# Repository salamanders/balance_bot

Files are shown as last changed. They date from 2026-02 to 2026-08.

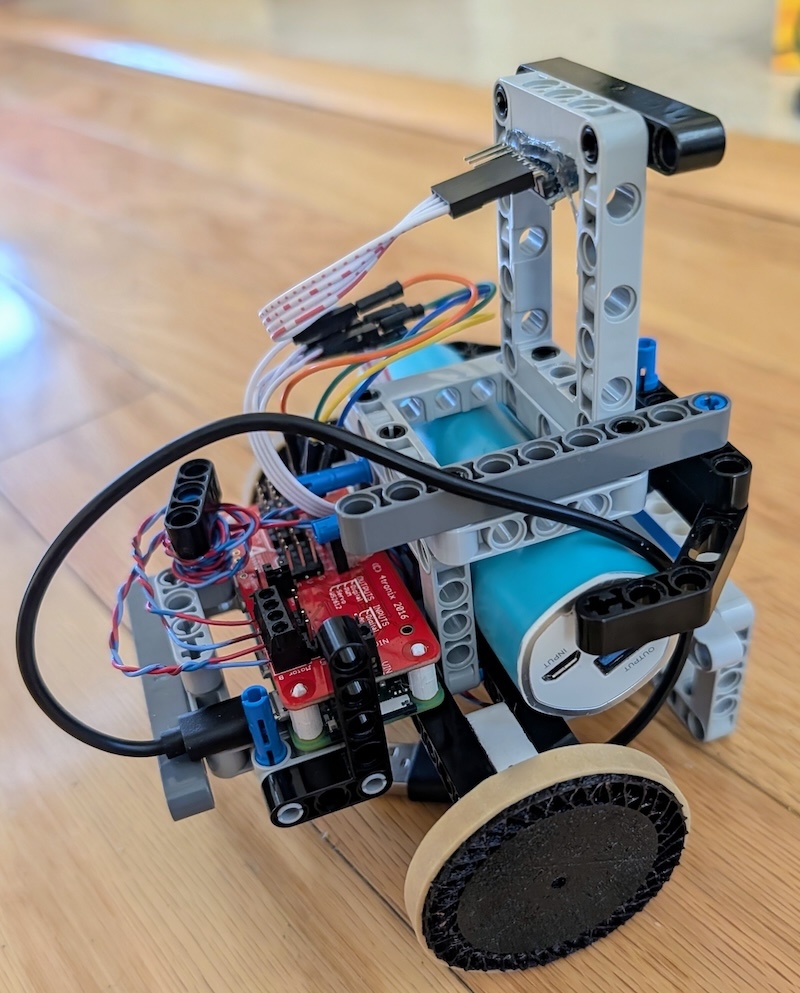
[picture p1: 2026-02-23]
robot.jpg

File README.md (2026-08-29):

# balance_bot

Self-balancing homebrew Segway robot powered by a Raspberry Pi, 4tronix PiconZero HAT, MPU-6050 IMU, and 3D-printed/LEGO mechanical topology.

> **Note for Developers and Autonomous Agents:**
> * For engineering governance, LLM directives, Multi-Mind subsumption architecture, Tabula Rasa self-discovery, empirical hardware rules, and codebase assumptions, see [AGENTS.md](file:///Users/benhill/Desktop/hobbies/balance_bot/AGENTS.md).
> * For the chronological log of physical experiments, hardware audits, bug investigations, and empirical lessons learned, see [JOURNAL.md](file:///Users/benhill/Desktop/hobbies/balance_bot/JOURNAL.md).

---

## References

### Root Directory

* [.gitignore](file:///Users/benhill/Desktop/hobbies/balance_bot/.gitignore): Git configuration specifying which files to ignore.
* [.python-version](file:///Users/benhill/Desktop/hobbies/balance_bot/.python-version): Specifies the Python version used by the project/tools.
* [AGENTS.md](file:///Users/benhill/Desktop/hobbies/balance_bot/AGENTS.md): Comprehensive engineering manual, LLM governance rules, system architecture, systemd auto-run instructions, and blind spot documentation.
* [JOURNAL.md](file:///Users/benhill/Desktop/hobbies/balance_bot/JOURNAL.md): Chronological engineering log of physical experiments, empirical hardware audits, bug investigations, and learnings.
* [LICENSE](file:///Users/benhill/Desktop/hobbies/balance_bot/LICENSE): Project license file.
* [Makefile](file:///Users/benhill/Desktop/hobbies/balance_bot/Makefile): Shortcut commands for installation, linting, formatting, and running.
* [README.md](file:///Users/benhill/Desktop/hobbies/balance_bot/README.md): The main entry point documentation.
* [environment.sh](file:///Users/benhill/Desktop/hobbies/balance_bot/environment.sh): Script to set up the development environment (system dependencies, uv).
* `pid_config.json`: Persisted storage for the tuned PID parameters.
* [pyproject.toml](file:///Users/benhill/Desktop/hobbies/balance_bot/pyproject.toml): Python project configuration, dependencies, and tool settings.
* [setup.sh](file:///Users/benhill/Desktop/hobbies/balance_bot/setup.sh): Initial system setup script (I2C enablement, system libraries).
* [uv.lock](file:///Users/benhill/Desktop/hobbies/balance_bot/uv.lock): Dependency lock file to ensure reproducible installs.

### Source Code (`src/balance_bot`)

**Core & Utilities**
* [src/balance_bot/__init__.py](file:///Users/benhill/Desktop/hobbies/balance_bot/src/balance_bot/__init__.py): Package initialization.
* [src/balance_bot/configuration.py](file:///Users/benhill/Desktop/hobbies/balance_bot/src/balance_bot/configuration.py): Centralized configuration (constants, dataclasses) for the robot.
* [src/balance_bot/enums.py](file:///Users/benhill/Desktop/hobbies/balance_bot/src/balance_bot/enums.py): Enumerations for direction and orientation.
* [src/balance_bot/jules_client.py](file:///Users/benhill/Desktop/hobbies/balance_bot/src/balance_bot/jules_client.py): Client for reporting crashes to Jules.
* [src/balance_bot/main.py](file:///Users/benhill/Desktop/hobbies/balance_bot/src/balance_bot/main.py): Main application entry point.
* [src/balance_bot/utils.py](file:///Users/benhill/Desktop/hobbies/balance_bot/src/balance_bot/utils.py): Shared utility functions (math, timing, filtering).
* [src/balance_bot/wiring_check.py](file:///Users/benhill/Desktop/hobbies/balance_bot/src/balance_bot/wiring_check.py): Interactive tool for verifying motor/sensor wiring and orientation.

**Tier 1: Reflex (Brainstem)**
* [src/balance_bot/reflex/balance_core.py](file:///Users/benhill/Desktop/hobbies/balance_bot/src/balance_bot/reflex/balance_core.py): The high-frequency (100Hz) balance loop. Pure physics/math.
* [src/balance_bot/reflex/pid.py](file:///Users/benhill/Desktop/hobbies/balance_bot/src/balance_bot/reflex/pid.py): PID controller implementation.

**Tier 2: Adaptation (Cerebellum)**
* [src/balance_bot/adaptation/recovery.py](file:///Users/benhill/Desktop/hobbies/balance_bot/src/balance_bot/adaptation/recovery.py): Soft-start logic for recovering from a crash.
* [src/balance_bot/adaptation/tuner.py](file:///Users/benhill/Desktop/hobbies/balance_bot/src/balance_bot/adaptation/tuner.py): Automatic PID tuning logic (Continuous Tuner) and Balance Point Finder.
* [src/balance_bot/adaptation/battery.py](file:///Users/benhill/Desktop/hobbies/balance_bot/src/balance_bot/adaptation/battery.py): Logic for monitoring battery voltage and estimating charge.

**Tier 3: Behavior (Cortex)**
* [src/balance_bot/behavior/agent.py](file:///Users/benhill/Desktop/hobbies/balance_bot/src/balance_bot/behavior/agent.py): The "Brain" that orchestrates the robot. Handles scheduling, state management, and high-level goals.
* [src/balance_bot/behavior/leds.py](file:///Users/benhill/Desktop/hobbies/balance_bot/src/balance_bot/behavior/leds.py): Controls the Raspberry Pi status LEDs for feedback.

**Hardware Abstraction**
* [src/balance_bot/hardware/robot_hardware.py](file:///Users/benhill/Desktop/hobbies/balance_bot/src/balance_bot/hardware/robot_hardware.py): Hardware Abstraction Layer (HAL) managing sensors and motors.
* [src/balance_bot/hardware/piconzero.py](file:///Users/benhill/Desktop/hobbies/balance_bot/src/balance_bot/hardware/piconzero.py): Driver for the Picon Zero Motor HAT.
* [src/balance_bot/hardware/piconzero_adapter.py](file:///Users/benhill/Desktop/hobbies/balance_bot/src/balance_bot/hardware/piconzero_adapter.py): Adapter for Picon Zero to manage I2C retries and bus switching.
* [src/balance_bot/hardware/mocks.py](file:///Users/benhill/Desktop/hobbies/balance_bot/src/balance_bot/hardware/mocks.py): Mock hardware implementations.

### Tests (`tests/`)
* [tests/benchmarks/](file:///Users/benhill/Desktop/hobbies/balance_bot/tests/benchmarks): Benchmark tests for performance critical components.
* [tests/test_balance_core_params.py](file:///Users/benhill/Desktop/hobbies/balance_bot/tests/test_balance_core_params.py): Tests for balance core parameters.
* [tests/test_balance_finder.py](file:///Users/benhill/Desktop/hobbies/balance_bot/tests/test_balance_finder.py): Tests for the Balance Point Finder logic.
* [tests/test_battery.py](file:///Users/benhill/Desktop/hobbies/balance_bot/tests/test_battery.py): Unit tests for battery estimation logic.
* [tests/test_i2c_config.py](file:///Users/benhill/Desktop/hobbies/balance_bot/tests/test_i2c_config.py): Tests for I2C bus configuration logic.
* [tests/test_imu_logic.py](file:///Users/benhill/Desktop/hobbies/balance_bot/tests/test_imu_logic.py): Tests for IMU math and pitch calculation.
* [tests/test_imu_resilience.py](file:///Users/benhill/Desktop/hobbies/balance_bot/tests/test_imu_resilience.py): Tests for IMU error handling and resilience.
* [tests/test_imu_yaw_roll.py](file:///Users/benhill/Desktop/hobbies/balance_bot/tests/test_imu_yaw_roll.py): Tests for yaw and roll calculations.
* [tests/test_kickup_config.py](file:///Users/benhill/Desktop/hobbies/balance_bot/tests/test_kickup_config.py): Tests for kick-up configuration and logic.
* [tests/test_piconzero_driver.py](file:///Users/benhill/Desktop/hobbies/balance_bot/tests/test_piconzero_driver.py): Tests for the Picon Zero driver.
* [tests/test_startup_logic.py](file:///Users/benhill/Desktop/hobbies/balance_bot/tests/test_startup_logic.py): Tests for the robot startup sequence.
* [tests/test_tuner.py](file:///Users/benhill/Desktop/hobbies/balance_bot/tests/test_tuner.py): Tests for the PID auto-tuning logic.
* [tests/test_utils.py](file:///Users/benhill/Desktop/hobbies/balance_bot/tests/test_utils.py): Unit tests for helper functions (clamp, filters, etc.).
* [tests/test_wiring_check_bus.py](file:///Users/benhill/Desktop/hobbies/balance_bot/tests/test_wiring_check_bus.py): Tests for the wiring check tool's bus detection.

### Printed Parts (`printed_parts/`)
* [printed_parts/dcmotor.scad](file:///Users/benhill/Desktop/hobbies/balance_bot/printed_parts/dcmotor.scad): OpenSCAD source file for motor mount.
* [printed_parts/tpu_wheel.scad](file:///Users/benhill/Desktop/hobbies/balance_bot/printed_parts/tpu_wheel.scad): OpenSCAD source file for TPU wheel.
* [printed_parts/wheel_v3.3mf](file:///Users/benhill/Desktop/hobbies/balance_bot/printed_parts/wheel_v3.3mf): 3D model project file (3MF) for the wheel (v3).
* [printed_parts/wheel_v3.scad](file:///Users/benhill/Desktop/hobbies/balance_bot/printed_parts/wheel_v3.scad): OpenSCAD source file for wheel v3.
* [printed_parts/wheel_v3_project.3mf](file:///Users/benhill/Desktop/hobbies/balance_bot/printed_parts/wheel_v3_project.3mf): Alternative/Project 3MF file for the wheel (v3).

---

## Getting Started (First Time Setup)

Follow these steps to get your robot up and running from a fresh Raspberry Pi installation.

### 0. Physical Wiring Check

* **MPU-6050**: VCC to 3.3V, GND to GND, SDA to SDA, SCL to SCL.
* **Motors**: Plugged into Motor A and Motor B on the Picon Zero.

If you have a Picon Zero HAT, it blocks standard I2C pins. You can add a software-defined "bus 3" using reachable GPIO pins:
1. Edit boot firmware configuration:
   ```bash
   sudo nano /boot/firmware/config.txt
   ```
2. Scroll to the bottom and add this exact line:
   ```txt
   dtoverlay=i2c-gpio,bus=3,i2c_gpio_sda=17,i2c_gpio_scl=27,i2c_gpio_delay_us=5
   ```
   *(Note: `i2c_gpio_delay_us=5` sets the bus speed to approximately 100kHz. Increase to `10` if you still encounter I2C errors.)*

### 1. Clone the Repository
```bash
git clone https://github.com/salamanders/balance_bot.git
cd balance-bot
```

### 2. Install `uv`
This project uses `uv` for Python dependency management:
```bash
curl -LsSf https://astral.sh/uv/install.sh | sh
```

### 3. System Setup
Run the setup script to enable I2C and install necessary system libraries:
```bash
chmod +x setup.sh
sudo ./setup.sh
```

### 4. Install Dependencies
```bash
uv sync
```

### 5. Verify & Run (Zero-Knowledge Self-Discovery)
Run the **Zero-Knowledge Self-Discovery Protocol**. This state-machine wizard automatically discovers your robot's unique motor wiring, polarity, MPU orientation, and friction thresholds on first boot:
```bash
uv run balance-bot
```
* The wizard is **pessimistic**: it verifies every discovery empirically before saving to `pid_config.json`.
* Once self-discovery completes, the main control loop wakes up and begins balancing automatically.
* For detailed documentation of the 7 self-discovery phases, see [AGENTS.md Section 5](file:///Users/benhill/Desktop/hobbies/balance_bot/AGENTS.md#5-the-tabula-rasa-protocol-zero-knowledge-self-discovery).

---

## CLI Execution & Flags

* `uv run balance-bot` — Runs standard self-discovery wizard or active balance control loop.
* `uv run balance-bot --deadman` — Enables the HTTP Deadman's Switch web interface (`http://<robot-ip>:8090`) for living room safety and remote data fetching.
* `uv run balance-bot --experiment-duration 4.0` — Enforces a global experiment timeout budget (e.g., 4.0s) across all phases.
* `uv run balance-bot --allow-mocks` — Runs control loop using Mock Hardware (required for CI / laptop testing without physical sensors/motors).
* `uv run balance-bot --reset-brain` — Wipes learned `pid_config.json` and forces re-running Tabula Rasa discovery.
* `uv run balance-bot --auto-fix` — Enables automated crash reporting and traceback submission to Jules.
* `uv run balance-bot --repl` — Launches interactive REPL for manual motor control, IMU reads, and gyro tests.

### Remote HTTP Data API (Port 8090)
When `--deadman` is active, the robot serves the following data endpoints over HTTP:
* `GET /flight_data.csv` (or `/data/flight`) — Raw 100Hz flight telemetry CSV.
* `GET /discovery_data.csv` (or `/data/discovery`) — Raw Tabula Rasa discovery calibration CSV.
* `GET /learning_state.json` (or `/data/learning_state`) — Current learned controller parameters and bumper angles.
* `GET /hardware_config.json` (or `/data/hardware_config`) — Physical hardware axis/bus mappings.
* `GET /data/analysis` — Automated blackbox forensic analysis JSON (kickup session breakdown, pulse metrics, failure classification).
* `GET /status` — Real-time pitch, posture, and deadman arming status.

---

## System Architecture, Governance & Empirical Rules

To eliminate duplication across documentation files, all system architecture details, multi-mind subsumption topology, AI agent governance directives, empirical hardware rules, systemd daemon deployment, and codebase assumptions are consolidated in [AGENTS.md](file:///Users/benhill/Desktop/hobbies/balance_bot/AGENTS.md):

* **[Project Philosophy & Hardware Reality](file:///Users/benhill/Desktop/hobbies/balance_bot/AGENTS.md#1-project-philosophy--hardware-reality)** — Bumpers, resting state vs. crash angle, kick-up maneuvers, and persistence.
* **[Mandatory LLM Directives & Code Standards](file:///Users/benhill/Desktop/hobbies/balance_bot/AGENTS.md#2-mandatory-llm-directives--code-standards)** — Pre-flight checks, type safety, SDD/RLVR, and anti-patterns.
* **[Mandatory Journaling Protocol](file:///Users/benhill/Desktop/hobbies/balance_bot/AGENTS.md#3-mandatory-journaling-protocol-journalmd)** — Requirements and formatting for logging experiments in `JOURNAL.md`.
* **[System Architecture & Multi-Mind Topology](file:///Users/benhill/Desktop/hobbies/balance_bot/AGENTS.md#4-system-architecture--multi-mind-topology)** — Tier 1 Brainstem (`100Hz`), Tier 2 Cerebellum (`~10Hz`), Tier 3 Cortex.
* **[Tabula Rasa Zero-Knowledge Bootstrapping](file:///Users/benhill/Desktop/hobbies/balance_bot/AGENTS.md#5-the-tabula-rasa-protocol-zero-knowledge-self-discovery)** — 7-phase self-discovery sequence and future Toddler Engine.
* **[Critical Cyber-Physical Blind Spots](file:///Users/benhill/Desktop/hobbies/balance_bot/AGENTS.md#6-critical-cyber-physical-blind-spots)** — Comprehensive comparison table of LLM biases vs. physical constraints.
* **[Immutable Empirical Hardware Rules](file:///Users/benhill/Desktop/hobbies/balance_bot/AGENTS.md#7-immutable-empirical-hardware-rules)** — PiconZero I2C register retention trap, LEGO mechanical backlash vs. `Kp`, tilt-chasing resonance in soft recovery, and the global 4-second chaos cutoff rule.
* **[Systemd Deployment & Automatic Startup](file:///Users/benhill/Desktop/hobbies/balance_bot/AGENTS.md#8-operations-systemd-deployment--manual-repl)** — Configuring `/etc/systemd/system/balance-bot.service` for auto-run on boot.
* **[Codebase Assumptions & Reference Citations](file:///Users/benhill/Desktop/hobbies/balance_bot/AGENTS.md#9-codebase-assumptions--reference-citations)** — I2C addresses, motor channels A/B, loop frequency, fall limit, default PID gains, and LED paths.

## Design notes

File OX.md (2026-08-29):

# OX.md - Balance Stabilization Strategy & Implementation Directive

> **Purpose:** This document is the authoritative engineering plan for achieving stable two-wheel
> balancing. It records the diagnosis, the reasoning behind every decision, the tradeoffs accepted,
> and the exact code changes required. It is written so that any agent (or human) can implement it
> without re-deriving the analysis.
>
> **Status:** Approved strategy (2026-08-22). Operator-confirmed dominant failure mode:
> **"Kick-up rarely succeeds - it never gets to vertical."**
> All downstream work (gains, damping, tuner) is unreachable until this gate is passed.
>
> **Governing rules:** All work must comply with [AGENTS.md](AGENTS.md) Sections 2, 6, and 7.
> Highlights enforced throughout this plan: no hardcoded physical constants, deadman switch AND/OR
> time budget on every physical trial, `make lint && make test` on all Python edits, mandatory
> JOURNAL.md entries per experiment, incrementalism over silver bullets, and confirmation of data
> interpretation with the operator before acting on telemetry.

---

## Table of Contents

1. [Diagnosis](#1-diagnosis-why-the-robot-cannot-balance)
2. [Strategy Overview & Phase Ordering](#2-strategy-overview--phase-ordering)
3. [Phase 0 Spec - Blackbox Forensics](#3-phase-0-spec---blackbox-forensics)
4. [Phase 1 Spec - State Estimation Fixes](#4-phase-1-spec---state-estimation-fixes)
5. [Phase 2 Spec - Rock-and-Flip Kick-Up](#5-phase-2-spec---rock-and-flip-kick-up)
6. [Phase 3+ Specs - Deferred Work](#6-phase-3-specs---deferred-work)
7. [Decision & Tradeoff Log](#7-decision--tradeoff-log)
8. [Validation Checklist & Journal Protocol](#8-validation-checklist--journal-protocol)

---

## 1. Diagnosis: Why The Robot Cannot Balance

Findings are ordered by causal priority. Each cites exact evidence locations.

### F0 - CRITICAL: The kick-up pulse collapses to ~one control tick (~10 ms)

**Evidence chain:**

* `src/balance_bot/behavior/states.py` lines 193-206 (`KickupState._incremental_kickup`):
  `context.core.hw.set_motors(drive_val, drive_val)` (pulse ON) immediately followed by
  `self._sleep_with_update(context, 0.25)` (intended 0.25 s pulse window).
* `states.py` lines 90 + 112-120: `_zero_motion_enabled` is
  `MotionRequest(velocity=0.0, turn_rate=0.0, enable_control=False)` and `_sleep_with_update`
  loops `context.core.update(self._zero_motion_enabled, ...)` every 10 ms.
* `src/balance_bot/reflex/balance_core.py` lines 149-163 (idle branch): when
  `motion.enable_control` is false the core **calls `self.hw.stop()` unconditionally, every tick**.

**Consequence:** On the first loop iteration after the pulse write, `core.update` writes zero.
The motor pulse lasts at most one loop period (`loop_time = 0.01 s`, configuration.py line 164)
plus I2C latency - not the intended 250 ms. A ~10 ms torque pulse cannot traverse LEGO gear
backlash, let alone rotate the chassis ~70 degrees from bumper rest to vertical. **This is the
leading hypothesis for the operator-confirmed failure mode.**

**Falsifiable prediction (verify in Phase 0 before touching anything):** in `flight_data.csv`,
each kick-up attempt should show non-zero `left_pwm`/`right_pwm` for only 1-2 consecutive rows.
If pulses actually last many rows, F0 is wrong; Phase 2 proceeds anyway (it removes the mechanism
entirely), but energy-delivery assumptions must be revisited.

### F1 - The kick-up sequence has no closed-loop timing

Independent of F0's duration bug, `_incremental_kickup` (states.py lines 173-221) fires a blind
fixed-duration pulse and only afterwards enters `_attempt_catch`. The robot never observes when
it crosses toward vertical:

* If the pulse carries the chassis past vertical sooner than assumed, gravity already pulls it
  over the wrong way before catch engages.
* If too weak, we wait out a full >= 1.25 s cycle (1.0 s settle + 0.25 s pulse + up to 2.5 s
  catch) before trying a bigger amplitude.
* With `kickup_power_forward/backward = 0.0` defaults (configuration.py lines 112-113), the
  search starts at zero power stepping 2% per cycle - tens of cycles, i.e., minutes, while the
  global `--experiment-duration` budget cuts runs short.

AGENTS.md Appendix A prescribes the fix ("Incremental Rock-and-Check Flip" with gyro feedback);
it was never implemented. Phase 2 implements it.

### F2 - Pitch estimate is corrupted exactly during kick-up/catch dynamics

`ComplementaryFilter` (utils.py lines 59-88) blends 2% raw accelerometer angle every tick
(alpha = 0.98, HardwareConfig line 165). During rotation, the MPU-6050 sits atop the tower
(r ~= 12-15 cm above the axle; AGENTS.md Rule 5), so tangential/centripetal acceleration dominates
the accelerometer and injects garbage into pitch precisely when closed-loop flip detection needs
it most. Additionally the filter initializes at `angle = 0.0` (utils.py line 75) while the robot
rests near -20 degrees on its bumpers; the 2 s warm-up (`setup_wait`) spends its early phase
recovering from a wrong prior instead of verifying calibration.

### F3 - The D-term is effectively absent (deferred - Phase 3a)

With degree units, `Kd = 0.5` contributes 30 PWM at a violent 60 deg/s fall rate while
`Kp = 10` contributes the same from only 3 degrees of tilt. An inverted pendulum is stabilized by
its derivative term; at these ratios the loop is nearly pure P, which on a backlash-y LEGO
drivetrain produces slam-oscillate-slam (JOURNAL 2026-08-02). Documented now so nobody re-litigates
it; addressed only after the kick-up gate passes.

### F4 - The auto-tuner cannot detect physical oscillation (deferred - Phase 3c)

`ContinuousTuner` analyzes a 1 s error buffer counting zero crossings against a 15% threshold
(configuration.py lines 65-66). A 1-2 Hz oscillation yields ~2-4 crossings per window - far below
threshold - so the "reduce Kp / boost Kd" heuristic rarely fires when needed. Kd nudges of +0.05
per event (50-tick cooldown) take many minutes of crashing to matter. Conclusion: **the tuner is a
trim tool, not a tuning tool**, and must not be relied on to rescue bad initial gains.

### F5 - No horizontal velocity handling (deferred - Phase 3b)

No encoders exist (PiconZero provides none), so once balanced the robot accelerates horizontally
until a wall or fall ends the run. Current mitigation (balance-point trim in
`BalancingState.update`, states.py lines 311-318) adjusts ~0.1 deg/s - orders of magnitude too slow
against runaway. Deferred until balancing itself works.

---

## 2. Strategy Overview & Phase Ordering

| Phase | Target | Changes behavior? | Gate to proceed |
| :--- | :--- | :--- | :--- |
| 0 | Blackbox forensics script | No (read-only tooling) | Operator confirms failure-mode data |
| 1 | Filter init + gyro-dominant blending | Yes (estimation only) | Lint/tests green; optional bench trial |
| 2 | Rock-and-Flip kick-up | Yes (state machine) | Kick-up success rate materially improves in trials |
| 3a | Gain restructuring (sim-first) | Yes (Tier 2 params) | Sim evidence; then hardware ladder |
| 3b | Velocity damping term | Yes (Tier 1 addition) | Baseline balance achieved |
| 3c | Auto-tuner demotion | Config only | Any time after 3a baseline |

**Ordering rationale:** the operator confirmed kick-up is the dominant failure, so everything
downstream has never been reached. Phases 0-2 attack exactly that gate. Phases 1 precedes 2
because closed-loop flip detection (Phase 2) depends on trustworthy pitch during motion (F2).
Gains are deliberately NOT touched until the robot reliably reaches vertical - changing two
variables at once destroys attribution, violating the incrementalism rule.

---

## 3. Phase 0 Spec - Blackbox Forensics

**Goal:** Confirm or falsify F0 and classify historical kick-up failures from existing telemetry,
with zero behavior change.

**Deliverable:** `tools/analyze_blackbox.py` (new directory; stdlib only - `csv`, `statistics`,
`argparse`. Note: `make lint` runs ruff on `src tests` only, but keep the script ruff-clean
anyway; mypy runs on `src` only).

**Input format** (from `src/balance_bot/telemetry.py` lines 39-50, file `flight_data.csv`,
one row per ~10 ms tick):

```
timestamp, state, pitch_angle, pitch_rate, yaw_rate, left_pwm, right_pwm, pid_target
```

**Required behavior:**

1. Segment rows by the `state` column transitions (`IdleState`, `KickupState`, `BalancingState`,
   `CrashedState`, `FatalErrorState`). Each contiguous `KickupState` block is one attempt session.
2. Within each session, detect pulses as maximal runs of rows where
   `abs(left_pwm) > 1.0 or abs(right_pwm) > 1.0`.
3. For every pulse report:
   * pulse width in ms (rows x ~10 ms) and peak PWM -> **directly verifies/falsifies F0**
     (prediction: width <= 20 ms);
   * max `abs(pitch_angle)` reached within 1.5 s after pulse onset ("how close to vertical");
   * min `abs(pitch_angle)` over the session (distance to vertical achieved);
   * whether `abs(pitch_angle) < 15.0` was ever reached (crossover zone entry).
4. Session summary: number of pulses, amplitude progression, outcome
   (entered BalancingState / crashed / budget-expired), time consumed.
5. Aggregate: counts per failure class -
   `NO_MOVEMENT` (peak |pitch| change < 3 deg after pulses),
   `INSUFFICIENT_ENERGY` (moved but never < 30 deg from vertical),
   `WRONG_TIMING` (crossed into zone but no BalancingState entry),
   `CAUGHT_THEN_LOST` (reached BalancingState then CrashedState).
6. Output a Markdown table to stdout plus an optional `--csv out.csv` summary.

**Acceptance:** runs on the existing `flight_data.csv` without error; results are reviewed with
the operator before Phase 2 parameters are chosen.

---

## 4. Phase 1 Spec - State Estimation Fixes

Two small changes confined to estimation. No gains, no state machine edits.

### 4a. Seed the filter from the actual rest angle

* **File:** `src/balance_bot/reflex/balance_core.py`
* **Change:** add method `seed_pitch_filter(self, samples: int = 100) -> None`: loop
  `self.hw.read_imu_converted()` `samples` times (no actuation), set
  `self.filter.angle = mean(reading.pitch_angle for readings)`.
* **Call site:** top of `Agent.run()` in `src/balance_bot/behavior/agent.py`, immediately BEFORE
  the warm-up while-loop (agent.py lines ~136-145). The robot must be at rest when this runs;
  log the seeded angle.
* **Why:** eliminates the wrong-prior transient so warm-up actually conditions the filter instead
  of slewing ~20 degrees.

### 4b. Gyro-dominant blending during high angular rate

* **File:** `src/balance_bot/utils.py` (`ComplementaryFilter.update`)
* **Signature change (backward compatible):**

  ```python
  def update(self, new_angle: float, rate: float, loop_delta_time: float,
             accel_norm_g: float | None = None) -> float:
  ```

* **Logic:** compute `alpha_eff`; start from `self.alpha`; if `accel_norm_g is not None` and
  `abs(rate) > self.rate_trust_limit`, use `self.gyro_only_alpha` (see config below).
  Then blend as today with `alpha_eff`.
* **Call site:** `balance_core.py` line ~147 continues to pass `(acc_angle, gyro_rate, dt)`.
  The accel-norm argument is accepted but NOT yet passed by Tier 1 (see tradeoff T4); the
  rate gate alone is active.
* **Config:** add to `HardwareConfig` (configuration.py, frozen model - additive fields are fine):

  ```python
  gyro_rate_distrust_limit: float = 60.0   # deg/s above which accel blending pauses
  gyro_only_alpha: float = 0.999           # near-pure gyro integration weight
  ```

  These are algorithm thresholds (not physical constants of a specific assembly), consistent
  with the Tabula Rasa rule; they ship as conservative defaults and persist via
  `hardware_config.json`.

* **Tests to update/add:** `tests/test_utils.py` (existing `ComplementaryFilter` coverage):
  new cases proving (i) below the limit behavior is bit-identical to today, (ii) above the limit
  the accelerometer term is suppressed, (iii) default construction keeps old signature working.
  Run `make lint && make test`.

---

## 5. Phase 2 Spec - Rock-and-Flip Kick-Up (The Main Event)

**Goal:** Replace the blind pulse + delayed catch with a closed-loop rock-and-flip that detects
vertical crossing in real time and engages catch control synchronously.

### 5a. New core primitive: `BalanceCore.pulse()`

* **File:** `src/balance_bot/reflex/balance_core.py`
* **Add method:**

  ```python
  def pulse(self, left_pwm: float, right_pwm: float, loop_delta_time: float) -> BalanceTelemetry:
      """One tick of open-loop actuation with full state estimation (no PID)."""
  ```

* **Behavior:** read IMU, update filter (exactly like `update()` steps 1-2), write motors via
  `self.hw.set_motors(clamped values)` (reuse the same clamp bounds as lines 247-249), populate
  and return `self.current_telemetry` with `motor_output=0.0`, `crashed=False`.
* **Safety inherited for free:** `hw.set_motors` already enforces deadman disarm
  (robot_hardware.py lines 495-498) and channel mapping fail-loud. The caller must still honor
  crash-angle checks and watchdog heartbeats.
* **Why this exists (T1):** pulses MUST NOT route through `update(enable_control=False)` - that is
  precisely the F0 bug (`stop()` every idle tick) - and MUST NOT run through PID (the controller
  would fight the pulse).

### 5b. New config fields

* **File:** `src/balance_bot/configuration.py`, class `ControlConfig` (lines 104-118). Add:

  ```python
  rock_amplitude_step: float = 2.0        # PWM % added per failed rock
  rock_pulse_max_duration: float = 0.40   # s hard cap per pulse
  rock_max_pulses: int = 6                # per KickupState entry (bounded search)
  crossover_zone_deg: float = 15.0        # |pitch| entering zone triggers flip check
  min_carryover_rate: float = 40.0        # deg/s needed to commit to the flip
  rest_settle_rate: float = 5.0           # deg/s below which robot counts as settled
  ```

* Start amplitude remains `kickup_power_forward/backward` if > 0, else
  `learning_state.min_power_visible + 10.0` (discovered floor plus margin; never hardcoded).
* Update `tests/test_kickup_config.py` to cover the new fields' defaults and persistence round-trip.

### 5c. Rewrite `KickupState` internals

* **File:** `src/balance_bot/behavior/states.py`
* **Remove:** `_incremental_kickup`'s blind pulse + post-hoc `_attempt_catch` sequencing.
  Keep `_attempt_catch` (its conservative gains at lines 132-142 are correct) but call it from
  the flip trigger instead of after a fixed sleep.
* **Keep:** public interface (`update(...)` signature), attempts accounting, transitions to
  `BalancingState`/`IdleState(attempts+1)`, watchdog heartbeat on EVERY tick.

**Algorithm (one KickupState entry):**

```
settle(): loop core.update(zero motion) until |pitch_rate| < rest_settle_rate
          for >= 0.5 s AND pitch within rest band; timeout 3 s; heartbeat each tick.

amplitude = start_amplitude(context)
for pulse_index in range(rock_max_pulses):
    direction = Direction.FORWARD if core.pitch < 0 else Direction.BACKWARD  # toward vertical
    drive = amplitude * float(direction.value)          # IntEnum arithmetic is safe
    rate = RateLimiter(1 / config.loop_time)
    pulse_deadline = now + rock_pulse_max_duration
    while now < pulse_deadline:
        watchdog.heartbeat()
        telem = core.pulse(drive, drive, dt)
        # Flip trigger: entered crossover zone WITH enough energy to carry over
        if abs(telem.pitch_angle) < crossover_zone_deg and \
           sign(telem.pitch_rate) matches rotation direction and \
           abs(telem.pitch_rate) >= min_carryover_rate:
            stop motors; return _attempt_catch(context, pid.target_angle)
        dt = rate.sleep()
    core.hw.stop()
    settle()
    # Failed rock: robot back on bumper? then grow amplitude; if it never moved,
    # also grow (same effect); abort only on rock_max_pulses exhaustion.
    amplitude += rock_amplitude_step
return False
```

**Critical correctness rules for the implementer:**

1. NEVER call `core.update(..., enable_control=False)` between `set_motors(pulse)` and the next
   intended pulse tick - that path stops the motors (this exact mechanism is bug F0).
   All pulse ticks go through `core.pulse()`.
2. The flip trigger must be evaluated on the SAME tick's telemetry it actuates after - no sleeps
   between detection and `_attempt_catch`. Catch latency budget: <= 1 loop tick (10 ms).
3. Every loop iteration must call `context.watchdog.heartbeat()` when a watchdog exists, matching
   existing patterns (states.py lines 101-102, 148-149, 195-196). The global
   `--experiment-duration` cutoff remains the outer safety net (AGENTS.md Rule 4).
4. Do not touch `IdleState` thresholds or attempt counting (3 attempts) in this phase;
   attribution requires one changed variable.
5. Type safety per `.jules/agent_instructions.md`: verify signatures before use; access enum
   numeric values explicitly (`float(direction.value)`); no unused imports after refactor
   (`_wait_for_settle` may become dead code - remove it and any now-unused imports).

### 5d. Tests (new file `tests/test_rock_flip_kickup.py`)

Model tests on the mocking style of `tests/test_agent_state_machine.py`. Build a FakeCore whose
`pulse()` advances a scripted physics trajectory (rest at -20 deg; given enough cumulative
pulse-ticks at amplitude A, pitch rises through the zone with rising rate; otherwise returns to
rest). Assert:

1. Pulse width spans MULTIPLE ticks before any stop (regression test for F0).
2. Flip trigger fires catch synchronously (no multi-hundred-ms gap) once trajectory enters zone.
3. Amplitude grows by `rock_amplitude_step` after each failed rock; bounded by `rock_max_pulses`.
4. Watchdog heartbeat called every tick; transition to BalancingState on catch success;
   IdleState(attempts+1) on failure.
5. `make lint && make test` green.

---

## 6. Phase 3+ Specs - Deferred Work

Do NOT start these until Phase 2 passes its hardware gate (kick-up success rate materially
improved across multiple trials, logged in JOURNAL.md).

### 3a. Gain restructuring (sim-first)

The pybullet rig (`src/balance_bot/simulation/sim_env.py`) already has torque control, domain
randomization (torque mods, IMU offset/rotation, jitter) and a 200 Hz physics / 100 Hz control
cadence - but nothing drives it with our controller (`sim_test.py` sends zeros). Build:

* `tools/sim_gain_sweep.py`: loads `PIDController` + the same error/D-term math used by
  `BalanceCore`, runs episodes over a gain grid (Kp in {8, 10, 14, 20}, Kd in {0.5, 2, 5, 10, 20},
  Ki = 0), emulating the discovered `min_power_visible` deadband on actuator output.
* Metrics per candidate: median episode survival time, RMS pitch, horizontal travel.
* Bring only the best 2-3 sets to hardware: one variable changed per trial, conservative baseline
  (`Kp=10, Ki=0, Kd=0.5`) as fallback between trials, deadman + experiment budget always on.
* Expected outcome (hypothesis to verify, not assume): final Kd well above 0.5 (see F3).

### 3b. Velocity damping term

Add a bounded damping contribution derived from high-pass-filtered forward acceleration
(pseudo-velocity; encoders are not available). Constraints:

* It is FEEDBACK DAMPING on estimated velocity - the target angle stays fixed at calibrated
  equilibrium. This does NOT violate the tilt-chasing prohibition (AGENTS.md Rule 3 /
  JOURNAL 2026-08-02): we never move the setpoint toward measured state.
* Authority clamp (max PWM contribution ~15) so sensor drift can never dominate.
* Tier 1 implementation must remain allocation-free and deterministic.

### 3c. Auto-tuner demotion

Until 3a's baseline is physically stable, set tuner aggression effectively to zero via config
(`start_aggression_normal` -> ~0 or a new enable flag). Rationale: F4 shows it cannot see the
oscillations that matter, and simultaneous tuner drift destroys attribution of hardware trials.
Reintroduce later strictly as a trim layer. Optional future: proper Astrom-Hagglund relay
autotune offline.

---

## 7. Decision & Tradeoff Log

| # | Decision | Alternatives rejected | Reasoning |
| :- | :--- | :--- | :--- |
| T1 | New `BalanceCore.pulse()` for open-loop ticks | Reuse `update()` with a new flag | `update(enable_control=False)` stops motors every tick - the exact F0 mechanism; adding flags there risks re-introducing it. A separate primitive makes "estimate + raw drive" explicit and keeps PID out of pulses. |
| T2 | Synchronous catch inside the pulse loop | Transition to a CatchState through the agent loop | State transition costs >= 1 agent-loop round trip plus Python overhead; catch latency budget is <= 1 tick (10 ms). `_attempt_catch` already runs its own tight loop - reuse it in place. |
| T3 | Incremental amplitude search retained | Single learned kick power persisted to config | Bumper geometry and floor friction differ per assembly/session; Tabula Rasa philosophy forbids trusting one learned constant. Search is bounded (6 pulses), so worst case is still time-limited. |
| T4 | Rate-gated gyro-dominant alpha only; accel-norm gate accepted but unwired | Full dynamic-alpha using accel magnitude deviation from 1 g | Unit ambiguity: real MPU-6050 library returns g, mocks/sim may differ; wiring an unscaled gate could permanently distrust the accelerometer. Defer until REPL empirically confirms each source's scale. |
| T5 | Stdlib-only analysis script in `tools/` | pandas/numpy notebook; package module | Zero new dependencies for a forensic tool; repo has numpy only under sim extras. |
| T6 | No encoder-based velocity feedback planned | Add encoders / different motor driver | Hardware constraint: PiconZero has no encoder inputs; AGENTS.md forbids assuming hardware swaps. Accel-derived pseudo-velocity is the only software path. |
| T7 | Freeze auto-tuner during kick-up trials | Let it co-adapt | Attribution: if gains drift while we change kick-up logic, trial results become uninterpretable; also F4 shows its nudges are noise at these timescales. |
| T8 | Gains untouched until kick-up gate passes | Fix F3 simultaneously | One changed variable per phase; historical sessions show multi-variable changes cannot be attributed (AGENTS.md incrementalism rule). |

---

## 8. Validation Checklist & Journal Protocol

For EVERY implemented phase:

1. `make lint` (ruff + mypy) and `make test` green before any hardware exposure.
2. Mock-mode smoke run: `uv run balance-bot --allow-mocks`.
3. Physical trials ONLY with `--deadman` engaged AND/OR `--experiment-duration` bounded
   (prefer both; AGENTS.md living-room safety rule).
4. Append a JOURNAL.md entry per trial using the template (Date, Hypothesis, Experiment,
   Observations, Learning, Action).
5. Run `tools/analyze_blackbox.py` after each trial; present the failure-class breakdown to the
   operator and CONFIRM interpretation before choosing next parameters.
6. Revert rule: any change that does not measurably improve its gate metric gets reverted before
   the next experiment (conservative-baseline discipline).
7. Never claim "this is the final fix" - record what was learned and what remains uncertain.

**Phase gates recap:** P0 -> operator-confirmed data picture; P1 -> estimation tests green;
P2 -> kick-up success observed on hardware; P3a -> sim-selected gains survive hardware ladder;
P3b/P3c -> only after stable baseline balancing exists.

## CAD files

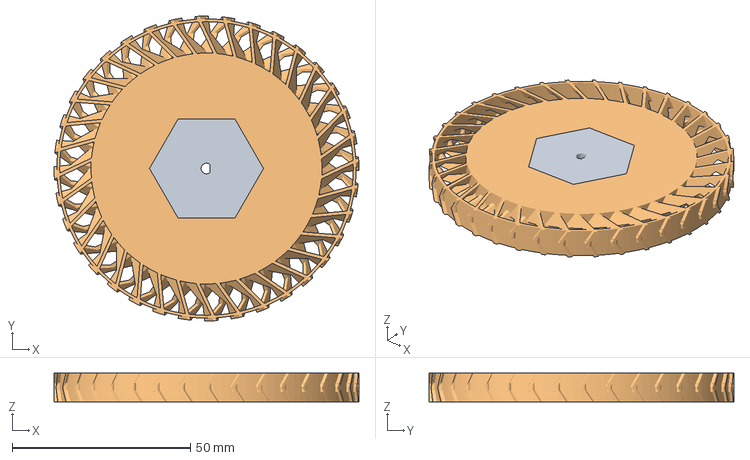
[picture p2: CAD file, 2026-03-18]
printed_parts/wheel_v3.3mf
85.6 x 85.6 x 8.00 mm

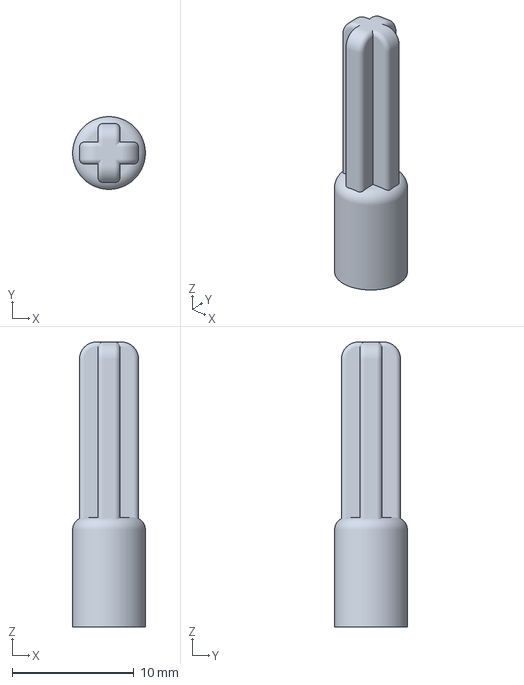
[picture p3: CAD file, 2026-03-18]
printed_parts/n20_to_technic.3mf
5.97 x 5.97 x 23.4 mm

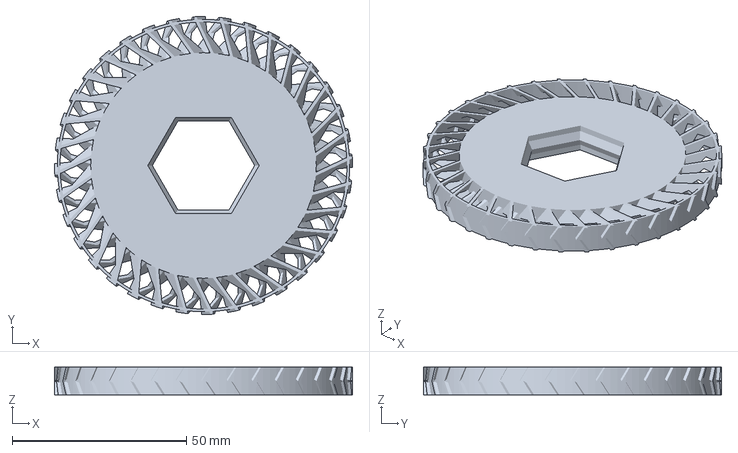
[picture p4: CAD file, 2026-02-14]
printed_parts/wheel_v3_project.3mf
85.6 x 85.6 x 8.00 mm

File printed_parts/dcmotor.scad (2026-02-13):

/* [Rendering] */
// Higher makes smoother circles. Use roughly 2x diameter for smooth prints.
$fn = 36; // *4 for final)

// Build outwards from the motor
overlap = 0.001;

// DC N20 motor dimensions
silver_height = 10;
silver_width = 12;
silver_depth = 27;


// SHAFT SETTINGS
// ------------------------------------------
// Measured diameter of your motor shaft (usually 3mm)
shaft_diameter = 3.0; 

// The "D" thickness (Distance from flat surface to opposite curved wall)
// For a 3mm shaft, this is usually 2.5mm. Measure yours with calipers!
shaft_flat_thickness = 2.5; 

// Printing Tolerance (Crucial!)
// 0.15mm - 0.2mm is usually good for a snug press fit.
fit_tolerance = 0.2;

shaft_length = 8;
//https://botland.store/n20-micro-motors-mp-series-medium-power/12606-micro-motor-n20-bt44-250-1-90rpm-6v-5904422306731.html

// Weel sections, all from center
press_fit_r = 6;
squish_r = 20;
paddle = squish_r + 10;

nozzle_diameter = 0.4;
wall_thickness = nozzle_diameter * 3;
num_vanes = 36; // Increased slightly to ensure smooth rolling on the tips
vane_thickness = 2*nozzle_diameter; 

// Controls the "V" shape on the tread (Ground smoothness)
chevron_angle = 35; 

// Controls the "Lean" of the soft (Torque Stiffness)
// 15-20 degrees is usually enough. Too high and it gets too stiff vertically.
truss_angle = 55; 


module zmirror(){
    children();
    mirror([0,0,1])
	children();
}

// 2. The D-Shaft Cutout (SUBTRACT)
module DShaft() {
    color("silver")
    translate([0,0, -shaft_length/2 - overlap]) // Center the cut vertically
    linear_extrude(height=shaft_length + overlap*2) {
        intersection() {
            // A. The Round Shaft
            circle(d = shaft_diameter + fit_tolerance, $fn=60);
            
            // B. The Flat Cut (The D-shape)
            // We draw a large square shifted to create the flat edge
            translate([ -shaft_diameter, -shaft_diameter ]) 
                square([ (shaft_flat_thickness + fit_tolerance) + shaft_diameter/2, shaft_diameter*2 ]);
        }
    }
}

// Motor block
*color("silver")
translate([0,0,-24/2 - shaft_length/2])
cube([10,12,24], center=true);

// Hard press-fit center
module PressFit_00() {
    color("FireBrick")
    difference() {
        intersection() {
            cylinder(h=shaft_length, r=press_fit_r, center=true, $fn=6);
            zmirror() {
                cylinder(h=shaft_length/2, r1=press_fit_r-1, r2=press_fit_r + 1, $fn=6);
            }
        }
        DShaft();
    }
}

PressFit_00();

difference() {
cylinder(h=shaft_length, r=squish_r, center=true);
cylinder(h=shaft_length+overlap*2, r=press_fit_r-1, center=true);
PressFit_00();
}

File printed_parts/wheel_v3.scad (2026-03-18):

/* [Rendering] */
// Higher makes smoother circles. Use roughly 2x diameter for smooth prints.
$fn = 120; // *4 for final

overlap_cut = 0.002;
nozzle_d = 0.4;


// DC N20 motor dimensions
//https://botland.store/n20-micro-motors-mp-series-medium-power/12606-micro-motor-n20-bt44-250-1-90rpm-6v-5904422306731.html
n20_shaft_length = 8;
n20_height = 10;
n20_width = 12;
n20_depth = 27;

// Wheel size
hub_outer_radius = 16; 
spoke_outer_radius = 32; 
tire_outer_radius = 42;

module n20_motor() {
    translate([0,0,-n20_shaft_length/2])
    union() {
        color("silver")
        translate([-n20_height/2,-n20_width/2,-n20_depth])
        cube([n20_height, n20_width, n20_depth]);
        
        // SHAFT SETTINGS
        // ------------------------------------------
        // Measured diameter of your motor shaft (usually 3mm)
        shaft_diameter = 3.0; 

        // The "D" thickness (Distance from flat surface to opposite curved wall)
        // For a 3mm shaft, this is usually 2.5mm. Measure yours with calipers!
        shaft_flat_thickness = 2.5; 
        

        color("silver")
        translate([0,0,-overlap_cut])
        intersection() {
            translate([0,0,n20_shaft_length/2 + overlap_cut])
            cylinder(h=n20_shaft_length + 2*overlap_cut, d=shaft_diameter, center=true);
            translate([-shaft_diameter/2, -shaft_diameter/2, 0])
            cube([shaft_flat_thickness,shaft_diameter,n20_shaft_length + 2*overlap_cut]);
        }
    }
 }

// Hard plastic
module Center_HardPlastic() {
    difference() {
        // Hex to avoid spinning.
        color("FireBrick")
        cylinder(h=n20_shaft_length, r=hub_outer_radius, $fn = 6, center=true);

        // Groove.
        rotate_extrude(convexity = 10, $fn=6)
        translate([hub_outer_radius + n20_shaft_length * .17, 0, 0])
        circle(d = n20_shaft_length * (2/3));        
    }
}

// Hard parts, PLA or PET-G
difference() {
    Center_HardPlastic();
    #n20_motor();
}


module HollowCylinder(h, r, r_inner) {
    difference() {
        cylinder(h=h, r=r, center=true);
        cylinder(h=h+overlap_cut, r=r_inner, center=true);
    }
}


num_vanes =36;
vane_thickness = nozzle_d*2; 
vane_angle = 35; 
herringbone_angle = 30;
vane_gap_r = tire_outer_radius - spoke_outer_radius;
// Extra because of the angle
vane_length = vane_gap_r * 3;
tread_r = nozzle_d*2;


module TiltedVanes(tilt=1) {
    color("purple")
    difference() {
        intersection() {
            union()
            for (i = [0 : num_vanes-1]) {
                rotate([0, 0, i * (360 / num_vanes)+0.4*tilt])
                translate([spoke_outer_radius, 0, 0])
                rotate([-herringbone_angle*tilt,0,vane_angle*tilt])
                // No Z offset, use the cylinder-carve to make a 50% herringbone
                translate([vane_length*0.2,0,0])
                cube([vane_length, vane_thickness, n20_shaft_length*2], center=true);
            }
            HollowCylinder(h=n20_shaft_length, r=tire_outer_radius+tread_r, r_inner=spoke_outer_radius);
        }
        // Notch for vanes
        translate([0,0,-n20_shaft_length*.6*tilt])
        rotate_extrude(convexity = 10)
        translate([spoke_outer_radius + vane_gap_r*.62, 0, 0])
        rotate([0,0,30])
        circle(r = vane_gap_r*.745, $fn=6); 
    }

    // fill some gaps
    color("orange")
    for (i = [0 : num_vanes-1]) {
        rotate([0, 0, i * (360 / num_vanes)+0.7])
        translate([tire_outer_radius, 0, 0])
        cylinder(h=n20_shaft_length*0.3, r=tread_r, center=true);
    }
    
}


module Squishy() {
    color("lightblue")
    cylinder(h=n20_shaft_length, r=spoke_outer_radius, center=true);
    
    color("ForestGreen")
    HollowCylinder(h=n20_shaft_length, r=spoke_outer_radius+nozzle_d, r_inner=spoke_outer_radius);
    
    TiltedVanes();
    
    TiltedVanes(-1);
    
    
    color("ForestGreen")
    HollowCylinder(h=n20_shaft_length, r=tire_outer_radius, r_inner=tire_outer_radius-nozzle_d*2);
    
}

 



difference() {
    Squishy();
    Center_HardPlastic();
}

/*


vane_length = vane_gap_r * sqrt(2);

module OuterVanesTop(herringbone_tilt = 1) {
    color("ForestGreen")
    cylinder(h=n20_shaft_length, r=spoke_outer_radius + nozzle_d*2);
    
    difference() {

    
    // "scoop"
    // Groove
    rotate_extrude(convexity = 10)
    translate([(tire_outer_radius + spoke_outer_radius)/2, 0, 0])
    circle(d = tire_outer_radius - spoke_outer_radius);         
    }
}


color("brown")
intersection() {
union() 
for (i = [0 : num_vanes-1]) {
    rotate([0, 0, i * (360 / num_vanes)])
    translate([spoke_outer_radius, 0, 0])
    rotate([herringbone_angle * 1,0,vane_angle])
    cube([vane_length +4, vane_thickness, n20_shaft_length], center=true);
}
cylinder(h=n20_shaft_length, r=tire_outer_radius);
}


module OuterVanes(){
    OuterVanesTop();
    translate([0,0,n20_shaft_length])
    rotate([180,0,6.8])
	OuterVanesTop(-1);
}



// Squishy parts, TPU
union() {
    difference() {
        OuterVanes();
        Middle_Squishy();
    }
    difference() {
        Middle_Squishy();
        Center_HardPlastic();
    }
}
*/

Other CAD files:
printed_parts/n20_to_technic.scad
printed_parts/tpu_wheel.scad

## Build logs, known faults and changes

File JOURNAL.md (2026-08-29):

# JOURNAL.md - Chronological Engineering & Experiment Log

> **Core Directive:** This journal is the single source of truth for all historical experiments, empirical hardware audits, bug investigations, and architectural lessons learned while developing the self-balancing robot.
> 
> **Mandatory Journaling Protocol:** Every time an agent attempts a physical calibration, modifies control loop dynamics, tests hardware drivers, or investigates a bug, you **MUST** append a new entry to this file documenting what was tried, what empirical evidence was observed, and what was learned. See [AGENTS.md Section 3](file:///Users/benhill/Desktop/hobbies/balance_bot/AGENTS.md#3-mandatory-journaling-protocol-journalmd).

## Table of Contents
1. [Purpose & Journaling Protocol](#purpose--journaling-protocol)
2. [Entry Template](#entry-template)
3. [Chronological Experiment & Audit Log](#chronological-experiment--audit-log)
   * [2025-02-18 - Refactoring Hardware Drivers with Global State](#2025-02-18---refactoring-hardware-drivers-with-global-state)
   * [2025-02-18 - Hardware Retry Logic Simplification & DRY](#2025-02-18---hardware-retry-logic-simplification--dry)
   * [2025-02-18 - Pruning Dead Vendor Code in src/](#2025-02-18---pruning-dead-vendor-code-in-src)
   * [2026-08-01 - Root Cause of Missing Attribute Error in icontract Decorators](#2026-08-01---root-cause-of-missing-attribute-error-in-icontract-decorators)
   * [2026-08-02 - The PiconZero I2C Register Retention Trap & Motor Runaway](#2026-08-02---the-piconzero-i2c-register-retention-trap--motor-runaway)
   * [2026-08-02 - LEGO Mechanical Backlash vs High Proportional Gain (Kp)](#2026-08-02---lego-mechanical-backlash-vs-high-proportional-gain-kp)
   * [2026-08-02 - The Tilt-Chasing Resonance Loop in Soft Recovery](#2026-08-02---the-tilt-chasing-resonance-loop-in-soft-recovery)
   * [2026-08-02 - Global vs. Local Safety Cutoffs (The 4-Second Chaos Rule)](#2026-08-02---global-vs-local-safety-cutoffs-the-4-second-chaos-rule)
   * [2026-08-02 - RateLimiter Busy-Wait vs time.sleep() Flakiness in CI](#2026-08-02---ratelimiter-busy-wait-vs-timesleep-flakiness-in-ci)
   * [2026-08-02 - Operational Guardrails & Next Horizon Hypotheses](#2026-08-02---operational-guardrails--next-horizon-hypotheses)

---

## Purpose & Journaling Protocol

In cyber-physical systems, code elegance is secondary to physical friction resolution. AI agents operating across distinct conversations lack memory of physical failures unless those outcomes are explicitly logged. By maintaining a structured, chronological journal of every experiment, we prevent repeating mistakes and build an empirical knowledge base for getting the robot balancing stably.

---

## Entry Template

When appending new entries to this file, use the following Markdown template:

```markdown
### YYYY-MM-DD - [Short Descriptive Title]
* **Hypothesis / Goal:** What we were trying to achieve or test.
* **Experiment / What We Tried:** The command, code change, or physical test executed.
* **Observations / Empirical Evidence:** What actually happened in hardware or logs.
* **Learning / Root Cause:** Why it happened and what principle was revealed.
* **Action / Rules Updated:** What changes were made to code, defaults, or AGENTS.md.
```

---

## Chronological Experiment & Audit Log

### 2025-02-18 - Refactoring Hardware Drivers with Global State
* **Hypothesis / Goal:** Refactor hardware driver modules (`piconzero.py`) while preserving testability in unit tests.
* **Experiment / What We Tried:** Unit testing modules that rely on module-level global state (`bus`, `DEBUG`, `RETRIES`) imported across multiple files.
* **Observations / Empirical Evidence:** Standard `unittest.mock.patch` failed when global state was initialized at import time; mocks did not cleanly isolate tests across test suites.
* **Learning / Root Cause:** When refactoring a module that relies heavily on global state and is imported by other modules, testing becomes tricky because the module is not fully reloaded between tests.
* **Action / Rules Updated:** When testing hardware drivers with global initialization, explicitly reload the module in `setUp` using `importlib.reload(module)` to ensure a clean state when the module initializes resources (`smbus.SMBus`) at the top level.

---

### 2025-02-18 - Hardware Retry Logic Simplification & DRY
* **Hypothesis / Goal:** Reduce repetitive error handling across hardware interface calls.
* **Experiment / What We Tried:** Audited error handling across `PiconZero` and `RobotHardware` methods.
* **Observations / Empirical Evidence:** Hardware drivers repeated try-except-retry error handling logic across dozens of methods, accounting for ~50% of boilerplate code.
* **Learning / Root Cause:** Repeating exception blocks around low-level I2C writes clutters the driver and leads to inconsistent error reporting.
* **Action / Rules Updated:** Refactored repeated `try...except` blocks in hardware interface code into a shared helper function `_retry(func, name)` early, halving code size while ensuring consistent retry behavior.

---

### 2025-02-18 - Pruning Dead Vendor Code in src/
* **Hypothesis / Goal:** Keep vendor-supplied driver files (`src/balance_bot/hardware/piconzero.py`) lean and maintainable.
* **Experiment / What We Tried:** Reviewed vendor files for unused methods and helper functions.
* **Observations / Empirical Evidence:** Vendor files contained extensive helper functions for lights, sensors, and peripherals not used by the balancing robot.
* **Learning / Root Cause:** Unused vendor code in `src/` increases maintenance burden, pollutes test coverage metrics, and confuses static analysis tools.
* **Action / Rules Updated:** Always check vendor files in `src/` for unused code and aggressively prune them if they are not maintained as an external dependency. Only keep motor control logic.

---

### 2026-08-01 - Root Cause of Missing Attribute Error in icontract Decorators
* **Hypothesis / Goal:** Investigate runtime error `AttributeError: 'MeasureResult' object has no attribute 'status'` during `repl.py` gyro testing.
* **Experiment / What We Tried:** Analyzed `@icontract.ensure(lambda result: result.status != 'unknown', ...)` on `drive_and_measure` in `robot_hardware.py` and `sim_hardware.py`.
* **Observations / Empirical Evidence:**
  1. `icontract` decorators accept lambda functions without generic type parameter bindings (`Callable[[T], bool]`). `mypy` treated the lambda argument `result` as `Any` and silently permitted `.status` access.
  2. Zero unit tests in `tests/` executed `drive_and_measure` or `test_gyro`, leaving the runtime contract unverified until manual REPL usage.
  3. `mypy` flagged `icontract`-decorated functions as untyped unless `--disallow-untyped-decorators` was enforced.
* **Learning / Root Cause:** Pure runtime contract decorators like `icontract` can hide static type errors inside lambdas. Without test coverage executing decorated functions, contract bugs slip through CI.
* **Action / Rules Updated:**
  * Every function decorated with `icontract` MUST have unit test coverage executing its happy path.
  * Prefer explicit helper validator functions (`def check_status(result: MeasureResult) -> bool: ...`) or Pydantic `@validate_call` where static type safety is preserved.

---

### 2026-08-02 - The PiconZero I2C Register Retention Trap & Motor Runaway
* **Hypothesis / Goal:** Ensure safe motor shutdown when the Python controller process is terminated or crashes.
* **Experiment / What We Tried:** Terminated the control process via `SIGTERM`, `SIGINT`, or `kill -9` while motors were actively driving.
* **Observations / Empirical Evidence:** The 4tronix PiconZero HAT uses an onboard ATmega328P microcontroller that holds its PWM output registers independently of the host Raspberry Pi CPU. When the host process terminated, the HAT continued driving motors indefinitely at the last commanded speed. Writing `0` to registers 0 and 1 over I2C was sometimes insufficient to override an active runaway state.
* **Learning / Root Cause:** Motor HAT microcontrollers decouple host CPU state from physical actuator state. Without an explicit hardware microcontroller reset, output pins remain energized.
* **Action / Rules Updated:** All hardware abstraction layers (`RobotHardware`) must register synchronous OS signal handlers (`SIGTERM` / `SIGINT`) and object destructors (`__del__`) that write both zero-power commands and the full board reset command (`CMD_RESET = 20` written to address `0x22`) before process termination.

---

### 2026-08-02 - LEGO Mechanical Backlash vs High Proportional Gain (Kp)
* **Hypothesis / Goal:** Test balancing responsiveness using standard aggressive proportional control (`Kp = 25.0`).
* **Experiment / What We Tried:** Ran inverted pendulum balance loop with default initial gain `Kp = 25.0`.
* **Observations / Empirical Evidence:** In a 3D-printed/LEGO Segway topology, mechanical gear backlash creates a physical deadband where the motor shaft rotates before teeth engage the wheel. At `Kp = 25.0`, a tiny 4° tilt error clamped PWM to 100%. The motor accelerated across the backlash gap, slammed into gear teeth, overshot the balance point, and caused violent oscillation.
* **Learning / Root Cause:** Stiff proportional control loops are incompatible with mechanical drivetrain backlash; high gains amplify deadband slam rather than correcting tilt.
* **Action / Rules Updated:** Never start balancing experiments at `Kp = 25.0`. Always begin at a conservative baseline (`Kp = 10.0`, `Ki = 0.0`, `Kd = 0.5`) that nudges wheels without slamming across backlash gaps.

---

### 2026-08-02 - The Tilt-Chasing Resonance Loop in Soft Recovery
* **Hypothesis / Goal:** Implement soft recovery by dynamically setting `target_angle_offset` to equal `current_pitch` when recovering from tilt error (`abs(pitch) > 5.0°`).
* **Experiment / What We Tried:** Dynamically updated `target_angle_offset` during active balancing in `BalancingState`.
* **Observations / Empirical Evidence:** Overriding the PID setpoint to match current pitch converted an inverted pendulum controller into an open-loop horizontal accelerator. Because maintaining non-zero tilt requires continuous horizontal acceleration, setting the target angle to match current wobble mathematically ordered the robot to accelerate across the floor at full speed ("jetting across the room"). As it bounced off walls, the target angle alternated signs, causing violent flailing.
* **Learning / Root Cause:** Setpoint tracking during active balance feedback loops creates positive acceleration resonance.
* **Action / Rules Updated:** Never override `target_angle_offset` during active balancing (`BalancingState`). Soft recovery ramps may only be applied once during wake-up from stationary rest; once in active balance, target angle must remain fixed at calibrated vertical equilibrium (`0.0°` plus trim).

---

### 2026-08-02 - Global vs. Local Safety Cutoffs (The 4-Second Chaos Rule)
* **Hypothesis / Goal:** Prevent robot from running open-loop or retrying indefinitely when calibration or kick-up fails.
* **Experiment / What We Tried:** Placed safety timeout logic inside individual state classes (`BalancingState`).
* **Observations / Empirical Evidence:** When the robot got trapped in earlier phases (e.g., `ProprioceptiveToddlerStep` discovery or `KickupState`), local state timeouts never fired, allowing the robot to crash into walls.
* **Learning / Root Cause:** Local state machine timeouts are bypassed when state transitions hang or loop in earlier calibration phases.
* **Action / Rules Updated:** Hard-cutoff timers (such as a 4.0-second maximum experiment limit) must be enforced at the root application/watchdog level (`main.py` / `SurvivalWatchdog`), independent of state-machine transitions, ensuring unconditional termination and hardware reset.

---

### 2026-08-02 - RateLimiter Busy-Wait vs time.sleep() Flakiness in CI
* **Hypothesis / Goal:** Validate 100Hz (`10ms` loop time) timing precision in unit tests and runtime.
* **Experiment / What We Tried:** Tested timing using standard Python `time.sleep()`.
* **Observations / Empirical Evidence:** `time.sleep()` only guarantees minimum sleep duration, not maximum. In CI environments or under CPU load (`pytest -n auto`), OS scheduler jitter caused `time.sleep()` to overshoot significantly, breaking 100Hz reflex determinism and flaking unit tests.
* **Learning / Root Cause:** Standard OS sleep functions are non-deterministic under load and cannot guarantee sub-millisecond precision required for inverted pendulum reflex loops.
* **Action / Rules Updated:** Use deterministic busy-waiting (`RateLimiter.sleep`) for real-time 100Hz execution. In unit tests, use mocked time (`patch("time.perf_counter")`) to deterministically verify rate limiter logic without flaky real-time dependencies.

---

### 2026-08-02 - Operational Guardrails & Next Horizon Hypotheses
* **Hypothesis / Goal:** Establish future safety guardrails and testable hypotheses as we advance toward robust balancing.
* **Experiment / What We Tried:** Formulated operational guardrails from empirical failure modes.
* **Observations / Empirical Evidence:**
  1. **Process Priority / Telemetry Server:** High-frequency Tier 1 loops can be starved by background tasks. Auxiliary servers must run with nice/ionice so they never preempt control:
     ```bash
     nohup nice -n 19 ionice -c 3 python3 -q -O -m http.server 8000
     ```
  2. **Gyro Failure Watchdog:** $N$ successive I2C gyro read failures indicates sensor bus lockup or disconnect $\rightarrow$ immediately halt all motors and stop.
  3. **Fall/Stall Detection:** $N$ successive motor move commands without any corresponding change in gyro rates indicates the robot has fallen over or stalled against an obstacle $\rightarrow$ immediately halt all motors and stop.
* **Learning / Root Cause:** Sensor disconnects and mechanical stalls require explicit watchdog detection independently of PID math.
* **Action / Rules Updated:** Prioritize implementing consecutive failure counters for gyro I2C reads and gyro-motor correlation checks in future `SurvivalWatchdog` enhancements.

---

### 2026-08-08 - Linting, Formatting, and Mac/Hardware-Agnostic Static Analysis
* **Hypothesis / Goal:** Establish robust, comprehensive linting (Ruff), code formatting, and strict type checking (MyPy) capable of running reliably in local macOS development environments without physical robot hardware or specialized device libraries attached.
* **Experiment / What We Tried:**
  1. Configured PyPI as the default `uv` package index (`[[tool.uv.index]] url = "https://pypi.org/simple"`) to ensure reproducible dependency syncing on macOS without failing on unauthenticated internal registries.
  2. Integrated `mypy>=1.14.0` alongside `ruff>=0.9.0` in `[dependency-groups] dev` within [`pyproject.toml`](file:///Users/benhill/Desktop/hobbies/balance_bot/pyproject.toml). Configured MyPy to ignore missing third-party hardware modules (`smbus2`, `mpu6050`, `pybullet`, `gymnasium`).
  3. Fixed missing `from typing import Any` and undefined names across `states.py`, `pipeline.py`, `balance_core.py`, and `watchdog.py`.
  4. Resolved real structural and protocol issues discovered by MyPy: added missing `is_verified()` method to `ProprioceptiveToddlerStep` (`CalibrationStep` protocol compliance), removed obsolete attribute access in `sim_hardware.py`, and ensured explicit type narrowing in `pid.py` and `robot_hardware.py`.
  5. Modernized deprecated `import glm` statements to `from pyglm import glm` across `src/` and `tests/`.
  6. Updated [`Makefile`](file:///Users/benhill/Desktop/hobbies/balance_bot/Makefile) with `lint`, `format`, `test`, `typecheck`, and `check` targets.
* **Observations / Empirical Evidence:** `make check` executes formatting verification (`ruff format --check`), linting (`ruff check`), static typing (`mypy src`), and the full unit test suite (`pytest tests/`), completing in ~4.5s with all 162 unit tests passing and 0 static analysis errors.
* **Action / Rules Updated:** Maintained `make lint`, `make format`, and `make check` workflows for local continuous verification.

---

### 2026-08-09: Cyber-Physical Bug Fixes & Control Loop Remediation
* **Hypothesis / Goal:** Resolve verified defects from [`POSSIBLE_ISSUES.md`](file:///Users/benhill/Desktop/hobbies/balance_bot/POSSIBLE_ISSUES.md): standardize deadman switch port, fix dead no-op catch checks and gain saturation during kick-up, correct inverted gyro pitch rate D-term sign in Tier 1 PID, apply stiction deadband compensation, and remove hardcoded balancing timeouts.
* **Experiment / What We Tried:**
  1. Standardized HTTP Deadman Switch port to 8090 across [`main.py`](file:///Users/benhill/Desktop/hobbies/balance_bot/src/balance_bot/main.py), [`deadman.py`](file:///Users/benhill/Desktop/hobbies/balance_bot/src/balance_bot/deadman.py), [`POSSIBLE_ISSUES.md`](file:///Users/benhill/Desktop/hobbies/balance_bot/POSSIBLE_ISSUES.md), and [`README.md`](file:///Users/benhill/Desktop/hobbies/balance_bot/README.md).
  2. Fixed dead `pass` statements in [`KickupState._attempt_catch`](file:///Users/benhill/Desktop/hobbies/balance_bot/src/balance_bot/behavior/states.py) to enable early success return upon vertical stability (`error < 5.0°` and low rate) and early abort on crash/overshoot (`error > 40.0°`).
  3. Clamped catch PID gains (`catch_kp = min(kp, 15.0)`, `ki = 0.0`, `catch_kd >= 0.5`) to eliminate LEGO gear backlash slamming and integral windup during kick-up transitions.
  4. Updated default `PIDParams.kp` from aggressive `25.0` to conservative baseline `10.0` in [`configuration.py`](file:///Users/benhill/Desktop/hobbies/balance_bot/src/balance_bot/configuration.py).
  5. Corrected gyro pitch rate D-term sign in [`PIDController.update`](file:///Users/benhill/Desktop/hobbies/balance_bot/src/balance_bot/reflex/pid.py) to `output += real_kd * measurement_rate` (preventing positive feedback damping inversion).
  6. Implemented actuator deadband feedforward compensation using `min_power_visible` in [`BalanceCore.update`](file:///Users/benhill/Desktop/hobbies/balance_bot/src/balance_bot/reflex/balance_core.py) to overcome static gear friction.
  7. Replaced hardcoded 4.0s cutoff in [`BalancingState`](file:///Users/benhill/Desktop/hobbies/balance_bot/src/balance_bot/behavior/states.py) with dynamic checks on `experiment_duration`.
* **Observations / Empirical Evidence:** Catch state now exits immediately when equilibrium is achieved or aborted on overshoot instead of spinning motors for 2.5s; gyro derivative acts in tandem with proportional drive rather than opposing it.
* **Learning / Root Cause:** Derivative on measurement in an inverted pendulum differs from standard setpoint regulation: positive angular velocity away from setpoint requires additive motor command in the direction of tilt to catch the center of gravity.
---

### 2026-08-22 - Full-Stack Stabilization Review; F0 Kick-Up Pulse Collapse Defect Found
* **Hypothesis / Goal:** Review entire control stack to explain operator-reported dominant failure mode ("kick-up rarely succeeds - never gets to vertical") and produce an actionable stabilization strategy (`OX.md`).
* **Experiment / What We Tried:** Read all MD files plus Tier 1 reflex loop (`balance_core.py`, `pid.py`, `utils.py`), HAL (`robot_hardware.py`), state machine (`states.py`, `agent.py`), adaptation modules, configuration defaults, simulation environment, and telemetry writer. Traced the kick-up execution path tick-by-tick.
* **Observations / Empirical Evidence:** Static trace found `_incremental_kickup` writes `set_motors(drive_val)` then calls `_sleep_with_update`, which loops `core.update(enable_control=False)` - and the idle branch of `BalanceCore.update` calls `hw.stop()` unconditionally every tick. The intended 250 ms kick-up pulse therefore collapses to ~one 10 ms loop period. Additional findings: no closed-loop flip timing (blind pulse + delayed catch); complementary filter blends accelerometer during high-rate dynamics and initializes at 0 deg instead of rest angle; D-term scale (Kd=0.5) far below stabilizing ratios; auto-tuner oscillation detector cannot see 1-2 Hz oscillation in a 1 s window.
* **Learning / Root Cause:** The idle branch's unconditional `stop()` is correct for safety but fatal when callers expect it to preserve manual motor writes. Any future open-loop actuation must use a dedicated primitive that performs estimation + raw drive without PID or idle-stop semantics.
* **Action / Rules Updated:** Wrote `OX.md` containing full diagnosis (F0-F5), phased plan (P0 blackbox forensics -> P1 estimation fixes -> P2 Rock-and-Flip kick-up -> P3 gains/damping/tuner), decision/tradeoff log (T1-T8), and validation checklist. No runtime code changed in this session. F0 falsification test defined: blackbox pulse widths should be <= 20 ms if F0 holds.
---

### 2026-08-28 - Implementation of Phase 0, 1, and 2: Closed-Loop Rock-and-Flip & State Estimation Remediation
* **Hypothesis / Goal:** Fix the F0 pulse collapse bug, implement Phase 1 state estimation enhancements (resting pitch seeding and rate-gated gyro-dominant filtering), build Phase 0 telemetry analysis tool (`tools/analyze_blackbox.py`), and implement Phase 2 closed-loop Rock-and-Flip kickup state with real-time crossover detection in `KickupState`.
* **Experiment / What We Tried:**
  1. **Phase 0:** Created `tools/analyze_blackbox.py` (stdlib only) to parse telemetry logs, isolate kickup sessions, measure pulse durations and peak PWM, and classify failure modes (`NO_MOVEMENT`, `INSUFFICIENT_ENERGY`, `WRONG_TIMING`, `CAUGHT_THEN_LOST`).
  2. **Phase 1a:** Added `BalanceCore.seed_pitch_filter(samples=100)` to measure the physical resting angle on the bumpers before sensor warmup in `Agent.run()`, preventing initial angle estimate slew transients.
  3. **Phase 1b:** Updated `ComplementaryFilter` in `utils.py` and `HardwareConfig` in `configuration.py` with `gyro_rate_distrust_limit = 60.0 deg/s` and `gyro_only_alpha = 0.999` to suppress corrupted accelerometer readings during high-angular-rate rotation. Added unit tests in `tests/test_utils.py`.
  4. **Phase 2a:** Implemented `BalanceCore.pulse(left_pwm, right_pwm, dt)` to execute open-loop motor actuation with real-time state estimation while eliminating the F0 `hw.stop()` cancellation bug. Added unit tests in `tests/test_balance_core_params.py`.
  5. **Phase 2b:** Added rock-and-flip parameters (`rock_amplitude_step`, `rock_pulse_max_duration`, `rock_max_pulses`, `crossover_zone_deg`, `min_carryover_rate`, `rest_settle_rate`) to `ControlConfig` in `configuration.py`. Updated `tests/test_kickup_config.py`.
  6. **Phase 2c:** Rewrote `KickupState` in `states.py` with closed-loop `_settle`, `_rock_and_flip`, and synchronous crossover detection that triggers `_attempt_catch` immediately when crossing into the $\pm 15^\circ$ zone with forward carryover angular rate.
  7. **Phase 2d:** Created `tests/test_rock_flip_kickup.py` with unit tests verifying continuous pulse execution across ticks (preventing F0 regression), synchronous catch transitions, amplitude progression, and watchdog heartbeats. Updated `tests/test_agent_state_machine.py` mocks.
  8. **HTTP Remote Data API:** Added REST endpoints to `DeadmanHandler` in `deadman.py` (`/flight_data.csv`, `/discovery_data.csv`, `/learning_state.json`, `/hardware_config.json`, and `/data/analysis`) to enable direct telemetry and forensics fetching over HTTP by remote agents/laptops. Added unit tests in `tests/test_deadman.py`.
* **Observations / Empirical Evidence:**
  - `BalanceCore.pulse()` ensures actuation persists for the full duration of pulses without being cancelled by the idle branch.
  - Settle routine ensures the robot is stationary on its bumper before applying pulse torque.
  - Closed-loop crossover trigger synchronizes catch activation with the pendulum crossing vertical.
  - Remote agents can fetch raw CSVs, configurations, and automated blackbox analysis JSON via HTTP without SSH/SCP.
* **Learning / Root Cause:** Decoupling open-loop actuation primitives from closed-loop PID updates prevents idle branch invariants (`hw.stop()`) from polluting transient state transitions, while real-time sensory gating eliminates blind time delays in cyber-physical actuation.
* **Action / Rules Updated:** Maintained fail-fast initialization, watchdog heartbeats per tick, and conservative defaults for all newly introduced parameters.

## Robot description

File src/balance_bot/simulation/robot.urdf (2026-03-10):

<?xml version="1.0"?>
<robot name="balance_bot">
  <!-- BASE LINK -->
  <link name="base_link">
    <visual>
      <!-- Shift center of mass slightly upward -->
      <origin xyz="0 0 0.05" rpy="0 0 0" />
      <geometry>
        <box size="0.08 0.1 0.1" />
      </geometry>
      <material name="blue">
        <color rgba="0 0 0.8 1" />
      </material>
    </visual>
    <collision>
      <origin xyz="0 0 0.05" rpy="0 0 0" />
      <geometry>
        <box size="0.08 0.1 0.1" />
      </geometry>
    </collision>
    <inertial>
      <!-- Assuming 200g base -->
      <mass value="0.2" />
      <origin xyz="0 0 0.05" rpy="0 0 0" />
      <inertia ixx="0.0002" ixy="0" ixz="0" iyy="0.0002" iyz="0" izz="0.0002" />
    </inertial>
  </link>

  <!-- DRAG BAR -->
  <link name="drag_bar">
    <visual>
      <origin xyz="0 0 -0.01" rpy="0 0 0" />
      <geometry>
        <!-- A thin box sticking out from the front and back near the bottom -->
        <box size="0.15 0.02 0.02" />
      </geometry>
      <material name="grey">
        <color rgba="0.5 0.5 0.5 1" />
      </material>
    </visual>
    <collision>
      <origin xyz="0 0 -0.01" rpy="0 0 0" />
      <geometry>
        <box size="0.15 0.02 0.02" />
      </geometry>
      <!-- High friction for the drag bar -->
      <surface>
        <friction>
          <ode>
            <mu>10.0</mu>
            <mu2>10.0</mu2>
          </ode>
        </friction>
      </surface>
    </collision>
    <inertial>
      <!-- Minimal mass for the drag bar -->
      <mass value="0.01" />
      <origin xyz="0 0 -0.01" rpy="0 0 0" />
      <inertia ixx="0.00001" ixy="0" ixz="0" iyy="0.00001" iyz="0" izz="0.00001" />
    </inertial>
  </link>

  <joint name="drag_bar_joint" type="fixed">
    <parent link="base_link" />
    <child link="drag_bar" />
    <origin xyz="0 0 0" rpy="0 0 0" />
  </joint>

  <!-- LEFT WHEEL -->
  <link name="left_wheel">
    <visual>
      <!-- Wheel is parallel to Y axis, rotate by pi/2 around X -->
      <origin xyz="0 0 0" rpy="1.57079632679 0 0" />
      <geometry>
        <!-- 60mm diameter -> 30mm radius, let's say 20mm width -->
        <cylinder radius="0.03" length="0.02" />
      </geometry>
      <material name="black">
        <color rgba="0.1 0.1 0.1 1" />
      </material>
    </visual>
    <collision>
      <origin xyz="0 0 0" rpy="1.57079632679 0 0" />
      <geometry>
        <cylinder radius="0.03" length="0.02" />
      </geometry>
    </collision>
    <inertial>
      <!-- 30g wheels -->
      <mass value="0.03" />
      <origin xyz="0 0 0" rpy="1.57079632679 0 0" />
      <inertia ixx="0.00001" ixy="0" ixz="0" iyy="0.00001" iyz="0" izz="0.00001" />
    </inertial>
  </link>

  <!-- RIGHT WHEEL -->
  <link name="right_wheel">
    <visual>
      <origin xyz="0 0 0" rpy="1.57079632679 0 0" />
      <geometry>
        <cylinder radius="0.03" length="0.02" />
      </geometry>
      <material name="black" />
    </visual>
    <collision>
      <origin xyz="0 0 0" rpy="1.57079632679 0 0" />
      <geometry>
        <cylinder radius="0.03" length="0.02" />
      </geometry>
    </collision>
    <inertial>
      <mass value="0.03" />
      <origin xyz="0 0 0" rpy="1.57079632679 0 0" />
      <inertia ixx="0.00001" ixy="0" ixz="0" iyy="0.00001" iyz="0" izz="0.00001" />
    </inertial>
  </link>

  <!-- CONTINUOUS JOINTS FOR WHEELS -->
  <joint name="left_wheel_joint" type="continuous">
    <parent link="base_link" />
    <child link="left_wheel" />
    <!-- Rotate around Y axis -->
    <axis xyz="0 1 0" />
    <!-- Offset on Y axis for wheel spacing -->
    <origin xyz="0 0.06 0" rpy="0 0 0" />
  </joint>

  <joint name="right_wheel_joint" type="continuous">
    <parent link="base_link" />
    <child link="right_wheel" />
    <!-- Rotate around Y axis -->
    <axis xyz="0 1 0" />
    <!-- Offset on Y axis for wheel spacing -->
    <origin xyz="0 -0.06 0" rpy="0 0 0" />
  </joint>

</robot>

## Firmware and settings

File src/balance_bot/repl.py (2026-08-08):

import argparse
import logging
import sys
import termios
import tty

from pyglm import glm

from balance_bot.configuration import HardwareConfig, LearningState
from balance_bot.hardware.robot_hardware import RobotHardware
from balance_bot.utils import analyze_dominance, average_vector

# Basic logging setup
logging.basicConfig(level=logging.INFO, format="%(message)s")
logger = logging.getLogger(__name__)


def getch() -> str:
    fd = sys.stdin.fileno()
    old_settings = termios.tcgetattr(fd)
    try:
        tty.setcbreak(sys.stdin.fileno())
        ch = sys.stdin.read(1)
    finally:
        termios.tcsetattr(fd, termios.TCSADRAIN, old_settings)
    return ch


class Repl:
    def __init__(self, allow_mocks: bool = False) -> None:
        if allow_mocks:
            import os

            os.environ["ALLOW_MOCK_FALLBACK"] = "1"

        self.config = HardwareConfig.load()
        self.state = LearningState.load()

        # If not initialized yet, we still need basic motor pins (e.g. 0 and 1)
        if self.config.motor_l is None or self.config.motor_r is None:
            updates = {"motor_l": 0, "motor_r": 1}
            self.config = self.config.model_copy(update=updates)

        # Force I2C buses to typical defaults if empty (Toddler Phase)
        if self.config.motor_i2c_bus is None or self.config.imu_i2c_bus is None:
            updates = {
                "motor_i2c_bus": self.config.motor_i2c_bus
                if self.config.motor_i2c_bus is not None
                else 1,
                "imu_i2c_bus": self.config.imu_i2c_bus
                if self.config.imu_i2c_bus is not None
                else 1,
            }
            self.config = self.config.model_copy(update=updates)

        self.hw = RobotHardware(self.config, self.state)
        self.speed = 50.0

    def print_help(self) -> None:
        print("\n--- Balance Bot Manual REPL ---")
        print("x : Switch left and right motor channels")
        print("l : Toggle left motor polarity")
        print("r : Toggle right motor polarity")
        print("+ : Increase speed by 10")
        print("- : Decrease speed by 10")
        print("w : Drive forward for 1 second")
        print("s : Drive backward for 1 second")
        print("a : Turn left 45 degrees (drives right wheel forward)")
        print("d : Turn right 45 degrees (drives left wheel forward)")
        print("g : Test gyro orientation using gravity and spin")
        print("f : Manually flop the robot to measure limits & print FULL REPORT")
        print("c : Show current polarity, channels, and speed")
        print("q : Exit REPL")
        print("? / h : Help")
        print("-------------------------------")

    def run(self) -> None:
        self.print_help()
        try:
            while True:
                print("\n> ", end="", flush=True)
                cmd = getch().lower()
                print(cmd)  # Echo the command

                if cmd in ["q", "\x03"]:  # q or Ctrl+C
                    break
                elif cmd == "x":
                    self._cmd_switch()
                elif cmd == "l":
                    self._cmd_flip_l()
                elif cmd == "r":
                    self._cmd_flip_r()
                elif cmd == "+":
                    self._cmd_speed_up()
                elif cmd == "-":
                    self._cmd_speed_down()
                elif cmd == "w":
                    self._cmd_fwd()
                elif cmd == "s":
                    self._cmd_back()
                elif cmd == "a":
                    self._cmd_turn_l()
                elif cmd == "d":
                    self._cmd_turn_r()
                elif cmd == "g":
                    self._cmd_test_gyro()
                elif cmd == "f":
                    self._cmd_flop()
                elif cmd == "c":
                    self._cmd_status()
                elif cmd in ["?", "h"]:
                    self.print_help()
                else:
                    print("Unknown command. Type '?' for help.")
        finally:
            self.hw.stop()

    def _cmd_switch(self) -> None:
        left_ch, right_ch = self.config.motor_l, self.config.motor_r
        # Keep invert flags with the wheel's physical location, not the channel ID?
        # Typically we just swap channels.
        new_config = self.config.model_copy(update={"motor_l": right_ch, "motor_r": left_ch})
        self.config = new_config
        self.hw.apply_config(self.config)
        print(f"Swapped! Left is now Channel {right_ch}, Right is Channel {left_ch}")

    def _cmd_flip_l(self) -> None:
        new_val = not self.config.motor_l_invert
        self.config = self.config.model_copy(update={"motor_l_invert": new_val})
        self.hw.apply_config(self.config)
        print(f"Left polarity is now {'INVERTED' if new_val else 'NORMAL'}")

    def _cmd_flip_r(self) -> None:
        new_val = not self.config.motor_r_invert
        self.config = self.config.model_copy(update={"motor_r_invert": new_val})
        self.hw.apply_config(self.config)
        print(f"Right polarity is now {'INVERTED' if new_val else 'NORMAL'}")

    def _cmd_speed_up(self) -> None:
        self.speed += 10.0
        print(f"Speed increased to {self.speed}")

    def _cmd_speed_down(self) -> None:
        self.speed = max(0.0, self.speed - 10.0)
        print(f"Speed decreased to {self.speed}")

    def _cmd_fwd(self) -> None:
        print(f"Driving FORWARD at {self.speed} for 1s...")
        self.hw.execute_maneuver([(self.speed, self.speed, 1.0)])

    def _cmd_back(self) -> None:
        print(f"Driving BACKWARD at {self.speed} for 1s...")
        self.hw.execute_maneuver([(-self.speed, -self.speed, 1.0)])

    def _cmd_turn_l(self) -> None:
        # Drives right wheel forward (turn left)
        print(f"Turning LEFT at {self.speed} for 0.5s...")
        self.hw.execute_maneuver([(0.0, self.speed, 0.5)])

    def _cmd_turn_r(self) -> None:
        # Drives left wheel forward (turn right)
        print(f"Turning RIGHT at {self.speed} for 0.5s...")
        self.hw.execute_maneuver([(self.speed, 0.0, 0.5)])

    def _cmd_test_gyro(self) -> None:
        from balance_bot.enums import Axis

        print("\nTesting Gyro Orientation...")
        print("1. Measuring gravity...")
        baseline_accel = self.hw.measure_gravity(1.0)

        print("2. Spinning robot (LEFT TURN) to measure gyro...")
        # L motor backward, R motor forward -> left spin
        res = self.hw.execute_maneuver([(-self.speed, self.speed, 0.5)])
        spin_gyro = average_vector([s.gyro_raw for s in res.samples if s.gyro_raw])

        if spin_gyro is None or glm.length(spin_gyro) < 5.0:
            print("Failed to detect spin. Is the robot resting on the ground?")
            return

        print("3. Deducing orientation...")
        # Up Vector is the gravity baseline
        vert_axis_name, _, _ = analyze_dominance(
            {"x": baseline_accel.x, "y": baseline_accel.y, "z": baseline_accel.z}, "Vertical"
        )
        accel_vertical_invert = getattr(baseline_accel, vert_axis_name) < 0

        # Gyro Yaw is the dominant axis during the spin
        yaw_axis_name, _, _ = analyze_dominance(
            {"x": spin_gyro.x, "y": spin_gyro.y, "z": spin_gyro.z}, "Yaw"
        )
        # For a left spin (counter-clockwise from above), the up vector should point OUT of the robot top.
        # So we align Yaw with Vertical conceptually.
        gyro_yaw_invert = (
            getattr(spin_gyro, yaw_axis_name) > 0
        )  # Left turn typically positive rate, if negative, invert

        # To get forward and pitch, we'd normally pulse forward/backwards, but here we'll just guess based on Vertical and Yaw being Z.
        # Assuming Y is forward/pitch, X is left/right roll.
        pitch_axis_name = "y" if yaw_axis_name != "y" else "x"
        fwd_axis_name = "x" if vert_axis_name != "x" and pitch_axis_name != "x" else "y"

        print(f"Vertical Axis: {vert_axis_name.upper()} (Invert: {accel_vertical_invert})")
        print(f"Yaw Axis:      {yaw_axis_name.upper()} (Invert: {gyro_yaw_invert})")

        updates = {
            "accel_vertical_axis": Axis(vert_axis_name),
            "accel_vertical_invert": accel_vertical_invert,
            "gyro_yaw_axis": Axis(yaw_axis_name),
            "gyro_yaw_invert": gyro_yaw_invert,
            "gyro_pitch_axis": Axis(pitch_axis_name),
            "accel_forward_axis": Axis(fwd_axis_name),
        }
        self.config = self.config.model_copy(update=updates)
        self.hw.apply_config(self.config)
        print("Gyro orientation updated in memory.")

    def _cmd_flop(self) -> None:
        print("\n--- Manual Flop Calibration ---")
        print("Hold the robot UPRIGHT. Press Enter to start reading angles...")
        input()

        print(
            "Now, slowly lean the robot FORWARD until it hits its mechanical limit (e.g. training wheels)."
        )
        print("Hold it there for a few seconds. Press Enter when done.")

        # Read max forward pitch
        input()
        reading = self.hw.read_imu_converted()
        fwd_angle = reading.pitch_angle
        print(f"Recorded Forward Angle: {fwd_angle:.2f} deg")

        print("\nNow, slowly lean the robot BACKWARD until it hits its mechanical limit.")
        print("Hold it there for a few seconds. Press Enter when done.")
        input()
        reading = self.hw.read_imu_converted()
        back_angle = reading.pitch_angle
        print(f"Recorded Backward Angle: {back_angle:.2f} deg")

        self.state.rest_angle_forward = fwd_angle
        self.state.rest_angle_backward = back_angle

        self.state.spatial_orientation_verified = True
        self.state.motor_direction_verified = True
        self.state.motor_phasing_verified = True
        self.state.motor_channels_verified = True

        self.config.save()
        self.state.save()

        print("\n=================================")
        print("          FULL REPORT            ")
        print("=================================")
        print("\n--- HardwareConfig ---")
        print(self.config.model_dump_json(indent=2))
        print("\n--- LearningState ---")
        print(self.state.model_dump_json(indent=2))
        print("=================================\n")
        print("Configuration saved to disk.")

    def _cmd_status(self) -> None:
        print(f"Channels : L={self.config.motor_l}, R={self.config.motor_r}")
        print(
            f"Polarity : L_invert={self.config.motor_l_invert}, R_invert={self.config.motor_r_invert}"
        )
        print(f"Speed    : {self.speed}")


def main() -> None:
    parser = argparse.ArgumentParser()
    parser.add_argument(
        "--allow-mocks", action="store_true", help="Allow fallback to mock hardware"
    )
    args = parser.parse_args()

    repl = Repl(allow_mocks=args.allow_mocks)
    repl.run()


if __name__ == "__main__":
    main()

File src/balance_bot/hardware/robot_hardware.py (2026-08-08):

"""
# System Context
This module is part of the `balance_bot` application, designed to control a self-balancing
homebrew robot. It relies on a deterministic, high-frequency control loop and pessimistic hardware interactions.

# Business Rules
- Fail-fast initialization: The system must crash loudly if physical hardware is missing or unresponsive during boot.
- Fault-tolerant control loop: Once Tier 1 is running (e.g., `BalanceCore`), transient I/O errors must not collapse the system; use continuous data quality metrics instead of fatal exceptions.
- Physical pessimism: Never hardcode physical constants; rely on zero-knowledge self-discovery to deduce configuration.

# Dependency Maps
- Relies on internal configuration (`HardwareConfig`, `LearningState`).
- Interfaces with Tier 1 (`BalanceCore`), Tier 3 (`Agent`), and physical hardware abstraction (`RobotHardware`).
"""

import contextlib
import logging
import os
import signal
import sys
import threading
import time
from collections import deque
from typing import Any, Protocol, runtime_checkable

from pydantic import validate_call
from pyglm import glm

from ..configuration import (
    BALANCING_THRESHOLD,
    REST_ANGLE_MAX,
    REST_ANGLE_MIN,
    HardwareConfig,
    LearningState,
)
from ..enums import Axis
from ..utils import average_vector, calculate_pitch, clamp, get_i2c_failure_report
from ..watchdog import SurvivalWatchdog
from .types import DriveCommand, IMUReading, MeasureResult

logger = logging.getLogger(__name__)

MOTOR_MIN_OUTPUT = -100
MOTOR_MAX_OUTPUT = 100


@runtime_checkable
class MotorDriver(Protocol):
    """
    Protocol for motor driver implementations.
    Allows swapping between real hardware (PiconZero) and Mocks.
    """

    def init(self) -> None:
        """Initialize the motor driver hardware."""
        ...

    def cleanup(self) -> None:
        """Release hardware resources."""
        ...

    def stop(self) -> None:
        """Stop all motors immediately."""
        ...

    def set_retries(self, retries: int) -> None:
        """Set the number of I2C retries."""
        ...

    def set_motor(self, motor: int, value: int) -> None:
        """
        Set speed for a specific motor.
        :param motor: Motor channel index (0 or 1).
        :param value: Speed (-100 to 100).
        """
        ...

    def set_motors(self, motor_0_val: int, motor_1_val: int) -> None:
        """
        Set speed for both motors simultaneously using a block write.
        :param motor_0_val: Speed for Motor 0 (-100 to 100).
        :param motor_1_val: Speed for Motor 1 (-100 to 100).
        """
        ...


@runtime_checkable
class IMUDriver(Protocol):
    """
    Protocol for IMU driver implementations.
    Abstracts specific sensor libraries (e.g. mpu6050).
    """

    def get_accel_data(self) -> glm.vec3:
        """
        Get raw accelerometer data.
        :return: glm.vec3.
        """
        ...

    def get_gyro_data(self) -> glm.vec3:
        """
        Get raw gyroscope data.
        :return: glm.vec3.
        """
        ...


class MPU6050Adapter:
    """
    Adapter for the mpu6050 library class to match IMUDriver protocol.
    """

    def __init__(self, sensor_instance: Any):
        """
        Initialize the adapter.
        :param sensor_instance: Instance of mpu6050 class.
        """
        self.sensor = sensor_instance
        # Open /dev/null once for the lifecycle of the adapter
        # This avoids opening/closing files 200 times a second in the 100Hz control loop
        self._devnull = open(os.devnull, "w")

    def __del__(self) -> None:
        """Cleanup the file handle when the adapter is destroyed."""
        if hasattr(self, "_devnull") and not self._devnull.closed:
            self._devnull.close()

    def get_accel_data(self) -> glm.vec3:
        """Get accelerometer data."""
        with contextlib.redirect_stdout(self._devnull):
            d = self.sensor.get_accel_data()
        return glm.vec3(d["x"], d["y"], d["z"])

    def get_gyro_data(self) -> glm.vec3:
        """Get gyroscope data."""
        with contextlib.redirect_stdout(self._devnull):
            d = self.sensor.get_gyro_data()
        return glm.vec3(d["x"], d["y"], d["z"])
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

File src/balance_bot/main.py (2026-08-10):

"""
# System Context
This module is part of the `balance_bot` application, designed to control a self-balancing
homebrew robot. It relies on a deterministic, high-frequency control loop and pessimistic hardware interactions.

# Business Rules
- Fail-fast initialization: The system must crash loudly if physical hardware is missing or unresponsive during boot.
- Fault-tolerant control loop: Once Tier 1 is running (e.g., `BalanceCore`), transient I/O errors must not collapse the system; use continuous data quality metrics instead of fatal exceptions.
- Physical pessimism: Never hardcode physical constants; rely on zero-knowledge self-discovery to deduce configuration.

# Dependency Maps
- Relies on internal configuration (`HardwareConfig`, `LearningState`).
- Interfaces with Tier 1 (`BalanceCore`), Tier 3 (`Agent`), and physical hardware abstraction (`RobotHardware`).
"""

import argparse
import datetime
import mmap
import os
import traceback
from typing import Any

from .behavior.agent import Agent
from .jules_client import CrashReport, JulesClient
from .utils import get_captured_logs, setup_logging
from .watchdog import SurvivalWatchdog


def parse_args() -> argparse.Namespace:
    """Parse command line arguments."""
    parser = argparse.ArgumentParser(description="Balance Bot Control")
    parser.add_argument("--reset-brain", action="store_true", help="Wipe all learned configuration")
    parser.add_argument(
        "--allow-mocks", action="store_true", help="Allow fallback to mock hardware"
    )
    parser.add_argument("--auto-fix", action="store_true", help="Report crashes to Jules")
    parser.add_argument("--repl", action="store_true", help="Start the interactive manual REPL")
    parser.add_argument(
        "--deadman",
        action="store_true",
        help="Enable HTTP Deadman's Switch web server for living room safety",
    )
    parser.add_argument(
        "--deadman-port",
        type=int,
        default=8090,
        help="Port for HTTP Deadman's Switch server (default: 8090)",
    )
    parser.add_argument(
        "--experiment-duration",
        type=float,
        default=None,
        help="Global experiment timeout budget in seconds (e.g. 4.0)",
    )
    return parser.parse_args()


def get_tail_telemetry(filepath: str, lines: int = 100) -> str:
    try:
        with open(filepath, "r+b") as f:
            if os.fstat(f.fileno()).st_size == 0:
                return "Telemetry file empty."
            mm = mmap.mmap(f.fileno(), 0, access=mmap.ACCESS_READ)

            # Read header
            header_end = mm.find(b"\n")
            if header_end == -1:
                return "Telemetry format invalid (no newline)."
            header = mm[: header_end + 1].decode("utf-8")

            # Find the last N lines efficiently without loading the whole file
            # Go to end
            pos = mm.size() - 1
            newline_count = 0

            while pos > header_end and newline_count <= lines:
                if mm[pos] == 10:  # b"\n"
                    newline_count += 1
                pos -= 1

            if pos <= header_end:
                pos = header_end
            else:
                pos += 2  # Move past the newline

            tail_lines = mm[pos:].decode("utf-8")
            mm.close()
            return header + tail_lines
    except Exception as e:
        return f"Telemetry irrecoverable: {e}"


def _reset_robot_memory() -> None:
    """Wipe all learned configuration."""
    print("Resetting Robot Memory...")
    from .configuration import HardwareConfig, LearningState

    HardwareConfig().save()
    LearningState().save()
    print("Brain reset complete. Entering Toddler Phase.")


def _run_discovery(watchdog: SurvivalWatchdog, deadman_server: Any = None) -> None:
    """Run the self-discovery pipeline (Toddler Phase)."""
    print("Incomplete knowledge detected. Initiating Discovery...")
    from .discovery.discover_buses import DiscoverBusesStep
    from .discovery.hardware_init import HardwareInitStep
    from .discovery.pipeline import SelfDiscoveryPipeline
    from .discovery.toddler_engine import ProprioceptiveToddlerStep

    steps = [
        DiscoverBusesStep(),
        HardwareInitStep(),
        ProprioceptiveToddlerStep(),
    ]
    pipeline = SelfDiscoveryPipeline(steps, watchdog, deadman_server=deadman_server)
    pipeline.run()
    # SelfDiscoveryPipeline finishes and cleans up the hardware locks safely.
    print("Discovery complete. Waking up Main Agent...")


def _handle_crash_reporting(e: Exception, bot_instance: Agent | None = None) -> None:
    """Gather state and report the crash to Jules."""
    print("\n!!! CRASH DETECTED !!!")
    print("Auto-Fix enabled. Gathering data for Jules...")

    # 1. Capture Traceback
    tb = traceback.format_exc()

    # 2. Capture Logs
    logs = get_captured_logs()

    # 3. Capture State
    state_info: dict[str, Any] = {"status": "Crashed before Agent init or in Utility"}
    if bot_instance:
        try:
            state_info = {
                "hardware": bot_instance.hw_config.model_dump(),
                "learning": bot_instance.learning_state.model_dump(),
                "runtime_ticks": bot_instance.ticks,
            }
        except (AttributeError, ValueError, TypeError):
            state_info["serialization_error"] = "Could not serialize bot config"

    # 4. Capture Libs
    import importlib.metadata

    libs = {dist.metadata["Name"]: dist.version for dist in importlib.metadata.distributions()}

    # 5. Capture Telemetry
    telemetry_data = "No telemetry data found."
    if os.path.exists("flight_data.csv"):
        telemetry_data = get_tail_telemetry("flight_data.csv", 100)

    # 6. Report
    client = JulesClient()
    report = CrashReport(
        error_msg=str(e),
        stack_trace=tb,
        logs=logs,
        state=state_info,
        libs=libs,
        telemetry=telemetry_data,
    )
    success, prompt = client.report_crash(report)

    if success:
        print("Crash report submitted to Jules. Check your dashboard for the new session.")
    else:
        try:
            ts = datetime.datetime.now().strftime("%Y%m%d_%H%M%S")
            filename = f"exception_report_{ts}.md"
            with open(filename, "w") as f:
                f.write(prompt)
            print(f"Crash report saved locally to {filename} (Jules upload failed).")
        except Exception as write_err:
            print(f"Failed to write local crash report: {write_err}")
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

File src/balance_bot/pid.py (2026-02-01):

from .config import PIDParams
from .utils import clamp


class PIDController:
    """
    Standard PID Controller implementation with Anti-Windup and Derivative-on-Measurement.

    Logic:
        Output = (Kp * Error) + (Ki * Integral) + (Kd * Derivative)
    """

    def __init__(self, params: PIDParams):
        """
        Initialize the PID Controller.
        :param params: Configuration parameters (Kp, Ki, Kd, limits).
        """
        self.params = params
        self.integral = 0.0
        self.last_error = 0.0

    def update(
        self,
        error: float,
        loop_delta_time: float,
        measurement_rate: float | None = None,
    ) -> float:
        """
        Calculate the next control output.

        Derivative Calculation Strategy:
         - If `measurement_rate` is provided (e.g., from Gyro), use it directly.
           D-term = -Kd * rate. (Derivative on Measurement).
           This avoids "derivative kick" when the target changes and is less noisy.
         - Otherwise, calculate derivative from error difference.
           D-term = Kd * (error - last_error) / dt.

        Integral Strategy:
         - Accumulate error * dt.
         - Clamp sum to `integral_limit` (Anti-Windup).

        :param error: Current error (Target - Measured).
        :param loop_delta_time: Time elapsed since last update (seconds).
        :param measurement_rate: (Optional) Rate of change of the process variable.
        :return: Computed control output.
        """
        self.integral += error * loop_delta_time
        # Anti-windup
        limit = self.params.integral_limit
        self.integral = clamp(self.integral, -limit, limit)

        if measurement_rate is not None:
            # Derivative on Measurement
            # d(Error)/dt = d(Setpoint - Process)/dt
            # If Setpoint is constant, d(Error)/dt = -d(Process)/dt
            derivative = -measurement_rate
        else:
            # Derivative on Error
            derivative = (
                (error - self.last_error) / loop_delta_time
                if loop_delta_time > 0
                else 0.0
            )

        output = (
            (self.params.kp * error)
            + (self.params.ki * self.integral)
            + (self.params.kd * derivative)
        )

        self.last_error = error
        return output

    def reset(self) -> None:
        """
        Reset the internal state.
        Clears accumulated integral and last error history.
        """
        self.integral = 0.0
        self.last_error = 0.0

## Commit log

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2026-01-26 Implement PID persistence and force calibration
    - Save PID values and target angle to `pid_config.json` after tuning.
    - Load config on startup to skip calibration if file exists.
    - Add `--force-calibration` CLI arg and `force_calibration.txt` check to override stored config.
    - Update AGENTS.md to mark features #1 and #5 as complete.
    [main.py, mocks.py]
2026-01-26 feat: implement LED feedback for robot status
    - Added `LedController` class in `src/balance_bot/leds.py` to handle system LED blinking.
    - Implemented status-based LED patterns:
    - Fast Blink (5-10Hz): Setup / Waiting for Vertical.
    - Slow Blink (2Hz): Tuning / Wobbling phase.
    - Solid On: Balancing / Ready.
    - Countdown: 3-2-1 blink sequence for recovery.
    - Refactored `src/balance_bot/main.py` to use `LedController` and removed console spam.
    - Updated `AGENTS.md` to mark feature as complete.
    [leds.py, main.py]
2026-01-26 Implement continuous PID tuning for self-improving balance
    - Add `ContinuousTuner` class in `src/balance_bot/tuner.py` to analyze error history.
    - Integrate tuner into `main.py` control loop to nudge Kp, Ki, Kd based on oscillation, stability, and steady-state error.
    - Persist improved PID config to `pid_config.json` on fall or exit.
    - Add unit tests in `tests/test_tuner.py`.
    [pid_config.json]
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2026-01-26 feat: Add wiring check script and software correction for motors/gyro
    - Created `src/balance_bot/wiring_check.py` interactive tool to verify motor direction and gyro orientation.
    - Updated `RobotConfig` to support motor inversion, gyro axis selection, and gyro inversion.
    - Updated `RobotHardware` to apply motor inversion.
    - Updated `RobotController` to apply gyro axis selection and inversion.
    - Updated `AGENTS.md` to mark the task as complete.
    [config.py, main.py, robot_hardware.py]
2026-01-27 Refactor codebase for modernization and DRY
    - Modernized type hints to use built-in types (list, dict, tuple)
    - Refactored `RobotHardware` to centralize IMU processing logic (axis mapping, inversion, angle calc)
    - Updated `RobotConfig` to use `dataclasses.asdict` for nested JSON saving, with backward compatibility for legacy flat loading
    - Added `integral_limit` to `PIDParams`
    - Fixed `WiringCheck` to use shared IMU logic
    - Improved `RobotHardware` import logic to be test-friendly
    - Added tests for config migration and IMU logic
    [config.py, leds.py, main.py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]
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2026-01-27 Refactor codebase for cleanup and modernization
    - Replace `print` with `logging` in `RobotHardware`, `RobotConfig`, and `LedController`.
    - Extract magic numbers into class constants in `ContinuousTuner` and `BatteryEstimator`.
    - Add `LogThrottler` to `utils.py` and use it in `main.py` for low battery warnings.
    - Refactor `RobotConfig.load` to use a helper for dictionary filtering.
    - Refactor `LedController._find_led_path` to use a generator expression.
    - Fix logic in `BatteryEstimator` to use new constants.
    [battery.py, config.py, leds.py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]
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2026-01-28 Refactor piconzero module to modern Python standards
    - Convert `piconzero.py` from a legacy script to a `PiconZero` class.
    - Add type hinting, docstrings, and logging.
    - Use `smbus2` consistently.
    - Replace global state with instance attributes.
    - Rename methods to snake_case.
    - Update `RobotHardware` to use the new `PiconZero` class directly, removing the `PiconZeroAdapter`.
    - Modernize `battery.py` to use `clamp` utility.
    [battery.py, piconzero.py, robot_hardware.py]
2026-01-28 Refactor codebase for modern Python standards and configuration extraction
    - Extracted hardcoded LED and control constants into `LedConfig` and `ControlConfig`.
    - Integrated new configs into `RobotConfig` and `RobotController`.
    - Refactored `leds.py` to use `LedConfig` and `time.monotonic()`.
    - Modernized type hints and added docstrings in `piconzero.py`, `robot_hardware.py`, and `utils.py`.
    - Replaced magic numbers in `main.py` with config values.
    [config.py, leds.py, main.py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]
2026-01-29 Fix PID sign inversion and improve startup stability
    - Changed PID error calculation from `target - pitch` to `pitch - target` in `src/balance_bot/main.py`. This ensures that a forward lean (positive pitch) results in positive motor output (forward drive), which is required for balancing.
    - Added a `get_pitch()` call to the setup wait loop in `run_setup` to warm up the complementary filter before calibration.
    - Enhanced `src/balance_bot/wiring_check.py` to clarify the definition of "Forward" motor spin and added a warning to re-verify directions after swapping channels.
    [main.py]
2026-01-30 Improve out-of-the-box experience with better defaults and smart startup logic
    - Updated default PID values to Kp=25.0, Kd=0.5 for better initial stability.
    - Modified main.py to skip calibration/tuning if a config file exists.
    - Added --check-wiring and --tune CLI flags to main.py.
    - Integrated WiringCheck tool into main application flow via CLI flag.
    - Added safety warnings to wiring_check.py.
    - Updated startup logging to indicate "Production Mode" vs "First Run Mode".
    [config.py, main.py]
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2026-01-31 Add hardware diagnostics tool and --diagnose flag
    Added a new `src/balance_bot/diagnostics.py` module to perform low-level hardware checks (I2C tools, SMBus access, imports).
    Updated `src/balance_bot/main.py` to handle the `--diagnose` flag to run these checks.
    Updated `src/balance_bot/robot_hardware.py` to suggest running diagnostics when hardware initialization fails.
    [main.py, robot_hardware.py]
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2026-01-31 Enhance hardware diagnostics to be pessimistic and detailed.
    - Refactor `RobotHardware._init_hardware` to handle PiconZero and MPU6050 initialization failures separately.
    - Update `PiconZero` to raise exceptions on initialization failure instead of swallowing them.
    - Add `diagnostics.get_i2c_failure_report` to generate detailed error messages (checking bus existence, permissions, and `i2cdetect`).
    - Add tests for diagnostic reporting logic.
    [piconzero.py, robot_hardware.py, test_diagnostics.py]
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2026-02-01 Improve I2C failure error message
    Updated the "HARDWARE FAILURE" message in `src/balance_bot/diagnostics.py` to explicitly suggest checking the I2C bus configuration using the wiring check tool. This helps users who might be using a different I2C bus (e.g. Software I2C on Bus 3) realize they can switch it.
    Also updated the corresponding unit test in `tests/test_diagnostics.py`.
    [test_diagnostics.py]
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2026-02-01 Clean up legacy Picon Zero script and update documentation
    - Remove legacy `piconz.sh` script and its download/execution from `setup.sh`.
    - Update `src/balance_bot/piconzero.py` docstring to clarify it is the authoritative, modernized driver.
    - Update `README.md` to reflect these changes and point to the correct driver file.
    [piconzero.py]
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2026-02-01 Refactor control architecture to unified adaptive loop
    - Removed `RobotState` and explicit state machine from `main.py`.
    - Implemented `run_auto_calibrate` for interactive center-of-balance calibration.
    - Unified `run()` loop to handle balancing, tuning, and recovery dynamically.
    - Added `scale` parameter to `ContinuousTuner` for variable aggression ("temperature").
    - Implemented "First Run" logic: Kp=0, High Aggression, Auto-Calibration.
    - Updated `config.py` to remove unused legacy constants.
    - Updated `recover_from_rest` to work within the new loop structure.
    - Ensured `CRASH_ANGLE` is used for safety cutoffs and tuning eligibility.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
    [config.py, main.py, tuner.py]
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2026-02-02 Standardize on smbus2 and remove legacy smbus dependency
    - Removed `smbus` from project dependencies in `pyproject.toml`.
    - Implemented a compatibility shim in `src/balance_bot/__init__.py` to alias `smbus2` as `smbus` for `mpu6050-raspberrypi`.
    - Updated `src/balance_bot/hardware/piconzero.py` to use `smbus2` directly.
    - Updated `src/balance_bot/diagnostics.py` to check for `smbus2` and report correct library usage.
    - Updated `uv.lock`.
    [piconzero.py]
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2026-02-02 Fix bootstrap weakness and kick-up power consistency
    - Increased bootstrap Kp from 3.0 to 10.0 in `Agent._perform_discovery` to improve stability.
    - Added `kickup_power` to `ControlConfig` (mutable) to persist discovered kick-up force.
    - Updated `Agent._perform_discovery` to save `flop_power_fwd` to config.
    - Updated `Agent.run` to use configured `kickup_power` instead of hardcoded default.
    - Updated `RobotConfig` to use `default_factory` for mutable `ControlConfig`.
    - Added persistence test for `kickup_power`.
    [config.py, test_kickup_config.py]
2026-02-02 Refactor hardcoded strings to Enums
    Replaces usage of hardcoded strings ("front", "back", "left", "right", "x", "y", "z") and magic numbers (1.0, -1.0) with type-safe Enums across the codebase.
    - Introduces `src/balance_bot/enums.py` defining `Orientation`, `MotorSide`, `Axis`, and `Direction`.
    - Updates `RobotConfig` and `RobotHardware` to use `Axis` enum.
    - Updates `Agent` to use `Orientation` and `Direction` enums for discovery and kick-up logic.
    - Updates `WiringCheck` to use `MotorSide` and `Axis`.
    - Updates `tests/test_imu_logic.py` to use `Axis` enum.
    [config.py, enums.py, robot_hardware.py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]
2026-02-03 Refactor CRASH_ANGLE to config and harden safety logic
    - Moved global `CRASH_ANGLE` constant to `RobotConfig.crash_angle` and `TunerConfig.crash_angle` (default 60.0).
    - Renamed unused `RobotConfig.fall_angle_limit` to `crash_angle`.
    - Updated `BalanceCore`, `RobotHardware`, and `ContinuousTuner` to use the configurable crash angle.
    - Hardened `BatteryEstimator` against division-by-zero using epsilon check.
    - Updated `Agent` logic to prevent `BalancePointFinder` from running during intentional motion.
    - Fixed a broken relative import in `src/balance_bot/hardware/piconzero.py`.
    [balance_core.py, battery.py, config.py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]
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2026-02-05 feat: Add Jules Auto-Fix integration
    - Added `src/balance_bot/jules_client.py` to interface with Jules API.
    - Updated `src/balance_bot/utils.py` to capture recent logs in memory.
    - Updated `src/balance_bot/main.py` to catch exceptions, gather crash data (traceback, logs, state, libs), and trigger Jules session if `--auto-fix` is present.
    - Fixed broken import in `src/balance_bot/hardware/piconzero.py` discovered during diagnostics check.
    - Added `JULES_API_KEY` handling.
    [balance_core.py, jules_client.py, main.py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]
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2026-02-05 Optimize ContinuousTuner statistical analysis frequency
    - Add `analysis_interval` to `TunerConfig` (default 10).
    - Downsample statistical analysis in `ContinuousTuner` to run every N ticks.
    - Update tests to use `analysis_interval=1`.
    - Remove unused `CRASH_ANGLE` import in `balance_core.py`.
    - Add benchmark script `tests/benchmarks/test_tuner_perf.py`.
    [balance_core.py, config.py, tuner.py]
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2026-02-05 Optimize: Offload configuration saving to background thread
    Also fixes a bug in balance_core.py import.
    [balance_core.py]
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2026-02-06 Refactor I2C configuration to support separate buses for motors and IMU.
    - Replace `i2c_bus` with `motor_i2c_bus` and `imu_i2c_bus` in `RobotConfig` and `RobotHardware`.
    - Update `RobotConfig.load` to migrate legacy `i2c_bus` configuration automatically.
    - Update `WiringCheck` to independently scan for PiconZero and MPU6050 across candidate buses (1, 3, 0, 2).
    - Update `RobotHardware` to initialize drivers with their respective buses.
    - Update unit tests to reflect the new API and verify split-bus configuration support.
    [balance_core.py, config.py, robot_hardware.py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]
2026-02-06 Remove legacy i2c_bus configuration handling
    - Removed migration logic in `RobotConfig.load` for legacy `i2c_bus` field.
    - Updated `pid_config.json` to use `motor_i2c_bus` and `imu_i2c_bus`.
    - Fixed `MovementCheck` to use split bus fields when initializing `RobotHardware`.
    - Deleted `tests/test_config_migration.py` as it is no longer relevant.
    - Verified tests pass.
    [pid_config.json]
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2026-02-06 feat: introduce --allow-mocks flag for testing
    - Added `--allow-mocks` command line argument to `main.py`.
    - Updated `RobotHardware` to only fall back to mocks if `ALLOW_MOCK_FALLBACK` is set.
    - Removed auto-fallback behavior (loud crash if hardware is missing without the flag).
    - Updated tests to use `ALLOW_MOCK_FALLBACK`.
    - Updated `Makefile`, `README.md`, and `AGENTS.md` to reflect the new workflow.
    [pid_config.json]
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2026-02-07 Refactor PiconZero driver to remove unused I/O methods
    Removes unused methods for reading inputs, setting outputs, and controlling LEDs (NeoPixels) from the PiconZero driver. These features are not used by the balance bot and were identified as dead code. Also removes associated unused constants.
    Verification:
    - Ran `uv run ruff check .` to ensure no linting issues.
    - Ran `uv run pytest` to ensure no regressions in functionality.
    [piconzero.py]
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2026-02-07 Fix PiconZero driver to use individual byte writes for motor control
    Replaced the `write_i2c_block_data` call in `set_motors` with two individual `set_motor` calls (which use `write_byte_data`). This fixes an issue where the Picon Zero firmware failed to update motor speeds when using block writes.
    Added `tests/test_piconzero_driver.py` to verify the fix and prevent regressions.
    [piconzero.py, test_piconzero_driver.py]
2026-02-07 Refactor PiconZero to use a generic I2C retry helper
    - Introduce `_i2c_op` to encapsulate retry loop, exception handling, and logging.
    - Refactor `_write_byte`, `_write_block`, `_read_word` to use `_i2c_op`.
    - Add tests to verify retry logic works as expected.
    - Reduces duplicated code by ~20 lines and centralizes error handling logic.
    [piconzero.py, test_piconzero_driver.py]
2026-02-07 Remove unused movement methods in PiconZero driver
    This change removes the `forward`, `reverse`, `spin_left`, and `spin_right` methods from the `PiconZero` class in `src/balance_bot/hardware/piconzero.py`. These methods were unused by the `RobotHardware` abstraction and constituted dead code.
    This improves code health by clarifying the driver's interface and reducing maintenance burden.
    Verified by running `pytest tests/test_piconzero_driver.py` and the full test suite.
    [piconzero.py]
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2026-02-07 Rollback to legacy smbus and implement PiconZeroAdapter
    - Removed `smbus2` dependency and restored `smbus` (C-based) usage.
    - Created `PiconZeroAdapter` to wrap the vendor-provided `piconzero.py` module, avoiding direct modifications to the vendor file.
    - Updated `RobotHardware` to use `PiconZeroAdapter`.
    - Updated `WiringCheck` and `Diagnostics` to remove context manager usage (`with smbus.SMBus()`) which is not supported by legacy `smbus`.
    - Updated tests to verify adapter functionality and mock the new structure correctly.
    [robot_hardware.py, test_i2c_config.py, test_imu_yaw_roll.py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]
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2026-02-08 Fix I2C noise crashes with Zero-Order Hold strategy
    - Modified `RobotHardware.read_imu_raw` to catch `OSError` and return cached data.
    - Updated `WiringCheck` to safely ignore bad packets during calibration loops.
    - Added regression test for IMU resilience.
    [robot_hardware.py, test_imu_resilience.py]
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2026-02-08 Harden I2C drivers against infinite retries
    Modified `piconzero.py` to raise `OSError` after `RETRIES` attempts instead of failing silently.
    Updated `RobotHardware` to track consecutive IMU failures and raise `OSError` if `imu_max_retries` is exceeded (default 5).
    Added `imu_max_retries` to `RobotConfig` to allow tuning of sensor resilience.
    This prevents the robot from operating in a "zombie" state with stale sensor data or hanging indefinitely on motor commands.
    [balance_core.py, config.py, piconzero.py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]
2026-02-08 feat: Add safety catch to stop motors on crash
    Wraps the `Agent.run` method and the `Agent` lifecycle in `main.py` with `try...finally` blocks to ensure that `cleanup()` is called (stopping motors) even if the application crashes due to an unhandled exception.
    This prevents the robot from running away (continuing last motor command) if a crash occurs during warmup, calibration, or the main control loop.
    [main.py]
2026-02-08 feat: Implement ramping motor power check in Wiring Wizard
    - Added `min_power_visible` to `RobotConfig` (default 60).
    - Updated `WiringCheck.detect_i2c_buses` to pulse motors starting at power 20 and ramping up to 120 based on user input.
    - User can confirm movement ('y'), request more power ('m'), or reject bus/cancel ('n').
    - Updated `WiringCheck` setup methods to use the discovered `min_power_visible` instead of hardcoded 60.
    - Enhanced `tests/test_wiring_check_bus.py` with new tests for ramping logic and fixed test pollution by using `patch` on imported modules instead of `sys.modules`.
    [config.py]
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2026-02-08 Refactor wiring check and implement flop tests
    This change consolidates the setup wizard into `src/balance_bot/wiring_check.py`, replacing the deprecated `MovementCheck` and `--confirm-wiring` flag.
    Key changes:
    - Refactored `WiringCheck` to implement a 15-step interactive wizard including Bus Detection, Motor ID, Sensor Calibration, and new "Flop" tests.
    - Replaced `kickup_power` in `ControlConfig` with `kickup_power_forward` and `kickup_power_backward` to support asymmetric kick-up power requirements.
    - Updated `Agent` to use the new directional kick-up power settings based on starting pitch.
    - Removed `src/balance_bot/movement_check.py` and updated `main.py`.
    - Updated tests to reflect c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
    [config.py, main.py, test_kickup_config.py]
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2026-02-08 Refactor wiring check to remove time-sensitive user actions
    Replaces the time-limited gyro integration loop in `setup_static_sensors` with a two-step static accelerometer measurement (Back position, then Front position).
    Adds a `cross_product` helper to `utils.py` to calculate the pitch axis of rotation from the gravity vectors.
    This allows the user to tip the robot at their own pace without rushing.
    [utils.py]
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2026-02-09 Refactor piconzero driver to use _retry helper and fix debug scope bug
    [piconzero.py]
2026-02-09 Implement Zero-Knowledge Self-Discovery Wiring Check
    - Implements the protocol specified in `LEARN.md` within `src/balance_bot/wiring_check.py`.
    - Replaces the linear wiring check wizard with a state-machine loop that incrementally discovers bus addresses, sensor orientation, motor phasing, and kick-up thresholds.
    - Updates `RobotConfig` in `src/balance_bot/config.py` to support "Zero-Knowledge" state (optional axes, verification flags).
    - Updates `README.md` to document the new feature.
    - Updates tests in `tests/test_wiring_check_bus.py` to cover the new logic.
    [config.py]
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2026-02-11 Refactor PiconZero driver to use _retry helper
    Simplified error handling logic in `src/balance_bot/hardware/piconzero.py` by introducing a `_retry` helper function. This removes approximately 80 lines of duplicated code and ensures consistent retry behavior and error messaging across all hardware interaction methods. Also fixed a bug in `init()` where the `DEBUG` flag was not correctly updating the global variable.
    Tests were added and verified to ensure no regression in behavior.
    [piconzero.py]
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2026-02-14 Optimize Vector3 implementation using __slots__
    Replaced `Vector3` TypedDict with a `__slots__` based class in `src/balance_bot/utils.py` to reduce memory overhead and improve performance.
    Updated `cross_product` to use attribute access (`a.x`) instead of dictionary lookups.
    Updated `RobotHardware` (and `MPU6050Adapter`) to return `Vector3` objects.
    Updated `WiringCheck` and mocks to utilize the new `Vector3` class.
    Added benchmark `tests/benchmarks/benchmark_cross_product.py` showing performance improvement.
    Updated existing tests and added `tests/test_wiring_check_orientation.py`.
    [mocks.py, robot_hardware.py, test_imu_logic.py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]
2026-02-14 Fix piconzero.py: Remove duplication and fix syntax error
    - Deleted ~150 lines of duplicated code caused by a bad merge.
    - Fixed `IndentationError` in `_retry` function.
    - Preserved all auxiliary functions (lights, sensors) as required.
    - Verified with existing unit tests (`tests/test_piconzero_driver.py` and `tests/test_piconzero_internals.py`).
    [piconzero.py]
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2026-02-15 Fix I2C timing issues in PiconZero driver
    - Added 5ms sleep between retries in `_retry` helper to allow bus recovery.
    - Increased post-reset delay in `init()` from 10ms to 100ms for board stabilization.
    - Removed redundant `init_hw()` call in `WiringCheck.find_min_power` to prevent double resets.
    - Added regression tests in `tests/test_piconzero_internals.py` mocking `time.sleep`.
    - Fixed `tests/test_piconzero_driver.py` to robustly mock `smbus` for non-Pi environments.
    [piconzero.py, test_piconzero_driver.py]
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2026-02-16 Fix documentation discrepancies in README and config.
    - Update `README.md` to reference `crash_angle` (60 deg) instead of `fall_angle_limit` (45 deg).
    - Clarify in `README.md` that `gyro_pitch_axis` is discovered (default None), not assumed X.
    - Clarify in `README.md` that `min_pwm` is for battery estimation, while `min_power_visible` is the discovered physical deadband.
    - Update `ControlConfig` docstring in `src/balance_bot/config.py` to document `kickup_power_forward` and `kickup_power_backward` separately.
    [config.py]
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2026-02-16 Implement 'Proprioceptive Toddler' discovery engine
    - Created `src/balance_bot/discovery/` package with `DiscoveryBrain`, `DiscoveryContext`, and `Experiment` classes.
    - Refactored `RobotHardware` to support partial initialization (allowing `None` for axes/buses).
    - Updated `BalanceCore` to provide standard defaults for unconfigured hardware, ensuring backward compatibility.
    - Integrated discovery loop into `main.py` via `--discover` and `--reset-brain` flags.
    - Patched `wiring_check.py` for safer imports.
    - Added comprehensive tests for discovery logic and updated existing tests to match API changes.
    [balance_core.py, main.py, robot_hardware.py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]
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2026-02-17 Complete Proprioceptive Toddler (baby_brain) module.
    - Implemented Sensor Fusion Phasing logic in `ExpCrunch` to correctly identify gyro pitch inversion and accel forward axis.
    - Updated `DiscoveryContext.build_config` to utilize the new data from `ExpCrunch`.
    - Injected "Jules" persona (`[THOUGHT]`, `[SENSORY]`, `[LEARNED]`) into all discovery experiment logs.
    - Refactored `main.py` to use `argparse` and support the `--discover` flag with safety checks (`--force`).
    - Verified `RobotHardware` accepts `None` values for partial initialization during discovery.
    [main.py]
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2026-02-18 Simplify: Consolidate discovery logic into WiringCheck
    - Deleted `src/balance_bot/discovery/` package and `tests/test_discovery.py` (~1000 lines removed).
    - Updated `src/balance_bot/main.py` to use `WiringCheck` for `--discover`, `--force`, and `--reset-brain` flags.
    - Added `reset_hardware_map` to `RobotConfig` to support forced re-discovery.
    This removes the redundant "Proprioceptive Toddler" implementation in favor of the more robust `WiringCheck` implementation which handles all hardware discovery tasks including critical kick-up calibration.
    [config.py, main.py, types.py]
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
